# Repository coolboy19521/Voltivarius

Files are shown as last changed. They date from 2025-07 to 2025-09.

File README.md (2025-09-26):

# Voltivarius Komandasının Hesabatı




Bizim robotumuz **Raspberry Pi** bir-lövhəli kompüter ilə avtonom sürüş edir. Maneələri və hərəkətini təyin etmək üçün lidar, kamera, giroskop və məsafə sensorlarından istifadə edir. Robotun hərəkət etməsi üçün arxasında bir motor və bu motora qoşulmuş iki təkər vardır. Dönməsi üçünsə robotun qabağındakı servo motorundan və **Ackermann idarəetmə sistemindən** yararlanılır.

<h3>Komandamız</h3>

<table cellspacing="0" cellpadding="0" style="margin:0; padding:0; border-collapse:collapse;">
  <tr>
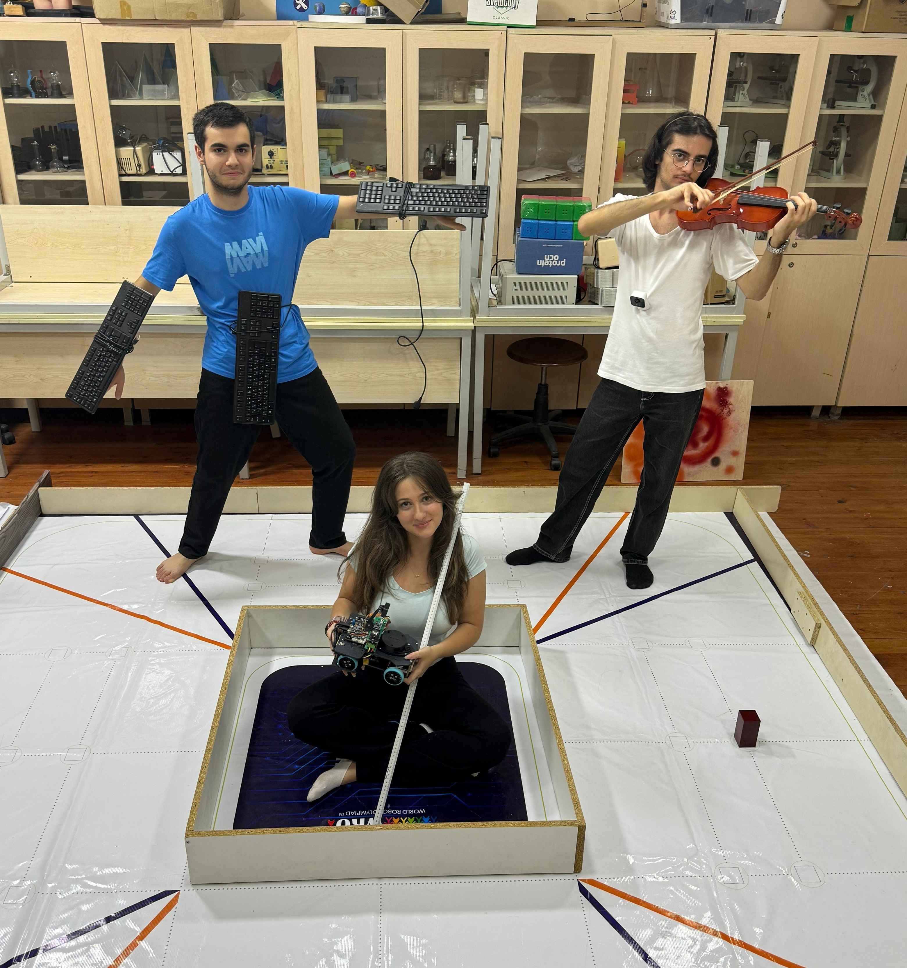
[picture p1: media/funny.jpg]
    <td style="margin:0; padding:0;"><br></td>
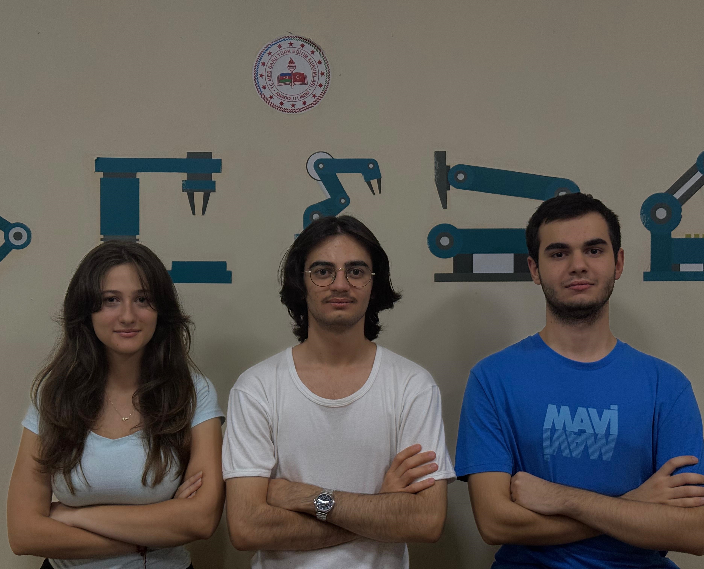
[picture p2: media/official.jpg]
    <td><br></td>
  </tr>
</table>

Komandamız **Əhməd Qəmbərli** (Proqramlaşdırma və strategiyanın təyin olunması; [ehmedqemberli09](mailto:ehmedqemberli09@gmail.com); rəsmi şəkildə sağda), **Melisa Yıldız** (Ümumi dizayn; [melisa.17.yildiz](mailto:melisa.17.yildiz@gmail.com); rəsmi şəkildə solda) və **Eyüp Şenal** (Elektronika, mexanika, detalların print olması və işlədilən məhsullar üçün bazar araşdırması; [arduinoaz2022](mailto:arduinoaz2022@gmail.com); rəsmi şəkildə mərkəzdə).

<h3>Robotumuz</h3>

<table cellspacing="0" cellpadding="0" style="margin:0; padding:0; border-collapse:collapse;">
  <tr>
    <td align="center" colspan="2">
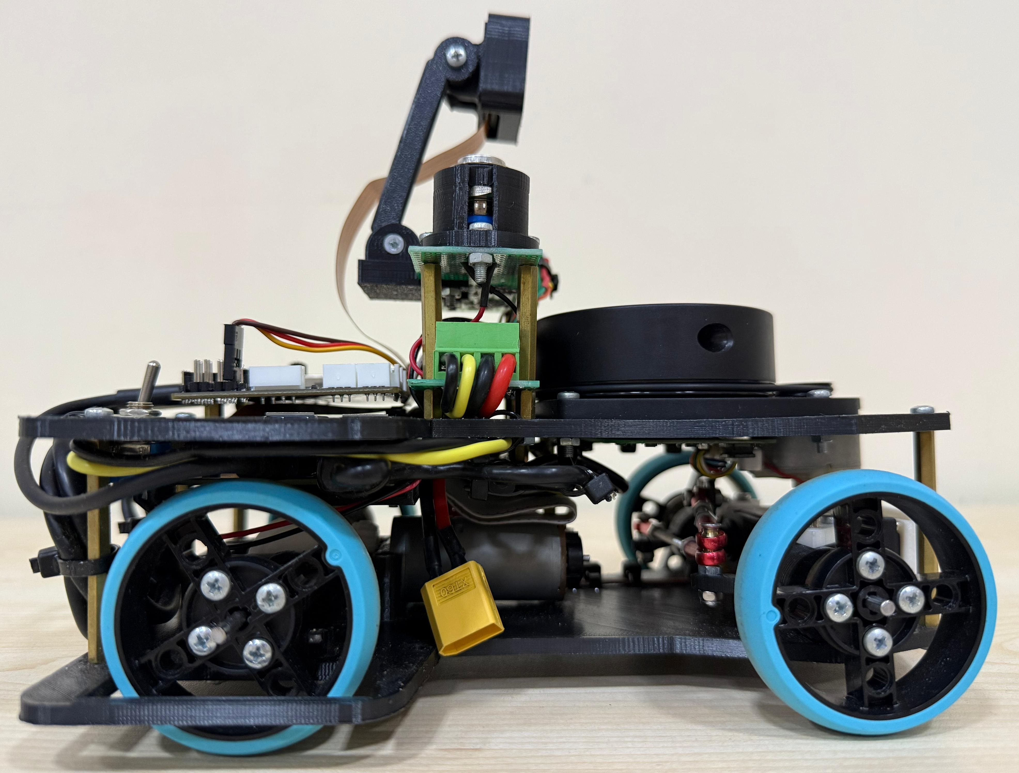
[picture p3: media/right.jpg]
      <br>
      <b>Sağ</b>
    </td>
    <td align="center" colspan="2">
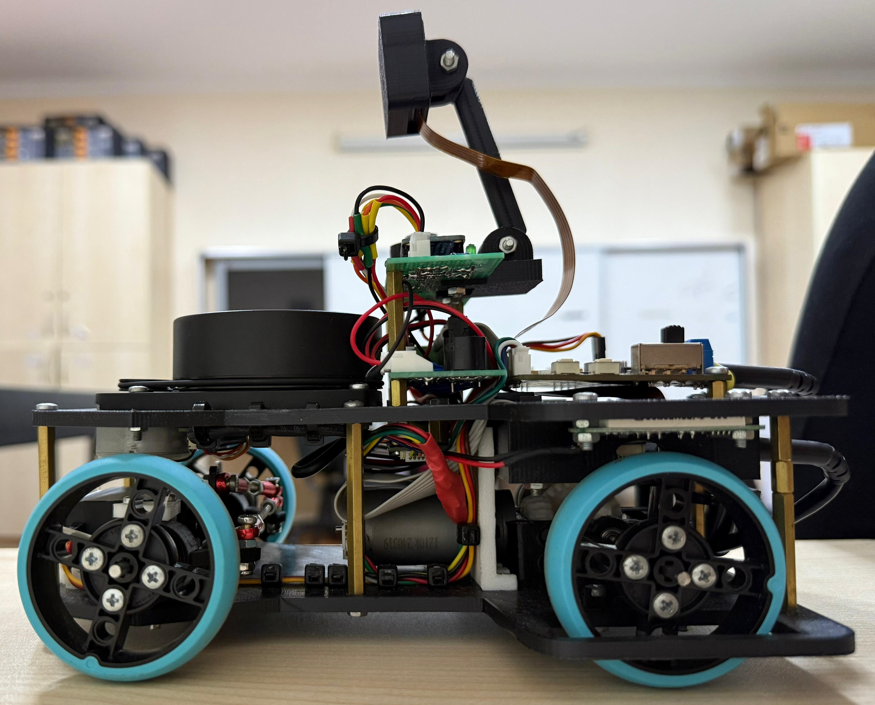
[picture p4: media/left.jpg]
      <br>
      <b>Sol</b>
    </td>
  </tr>
  <tr>
    <td align="center">
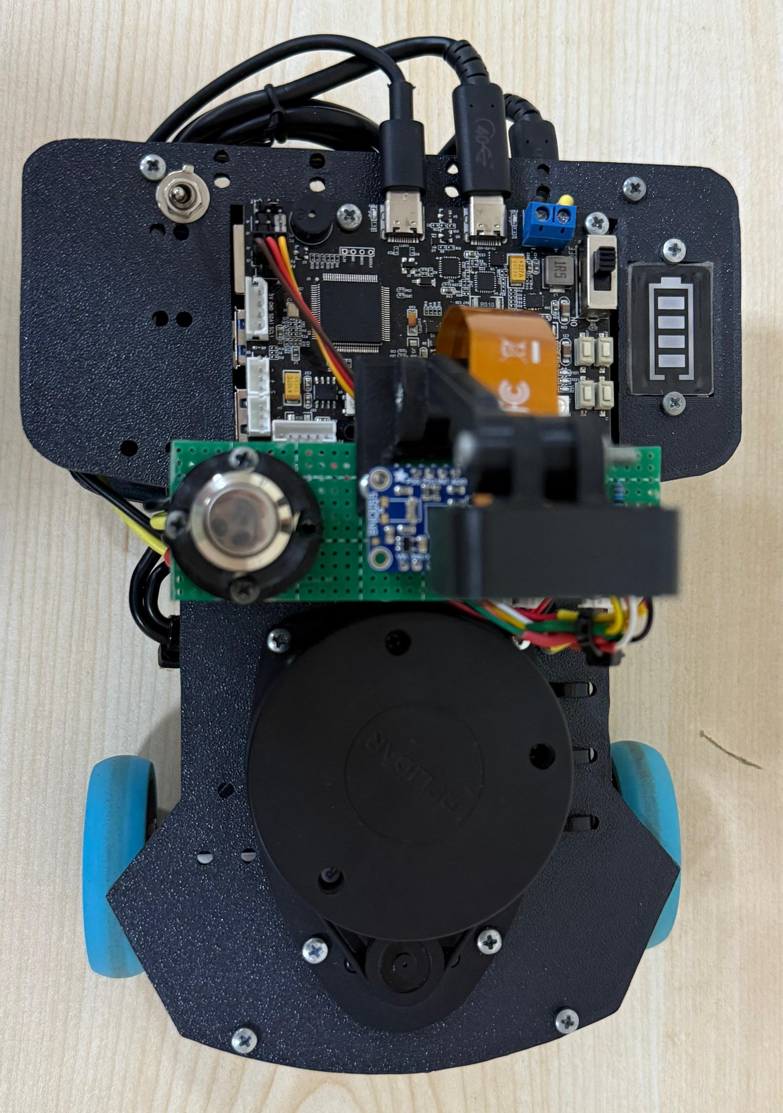
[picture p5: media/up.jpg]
      <br>
      <b>Üst</b>
    </td>
    <td align="center">
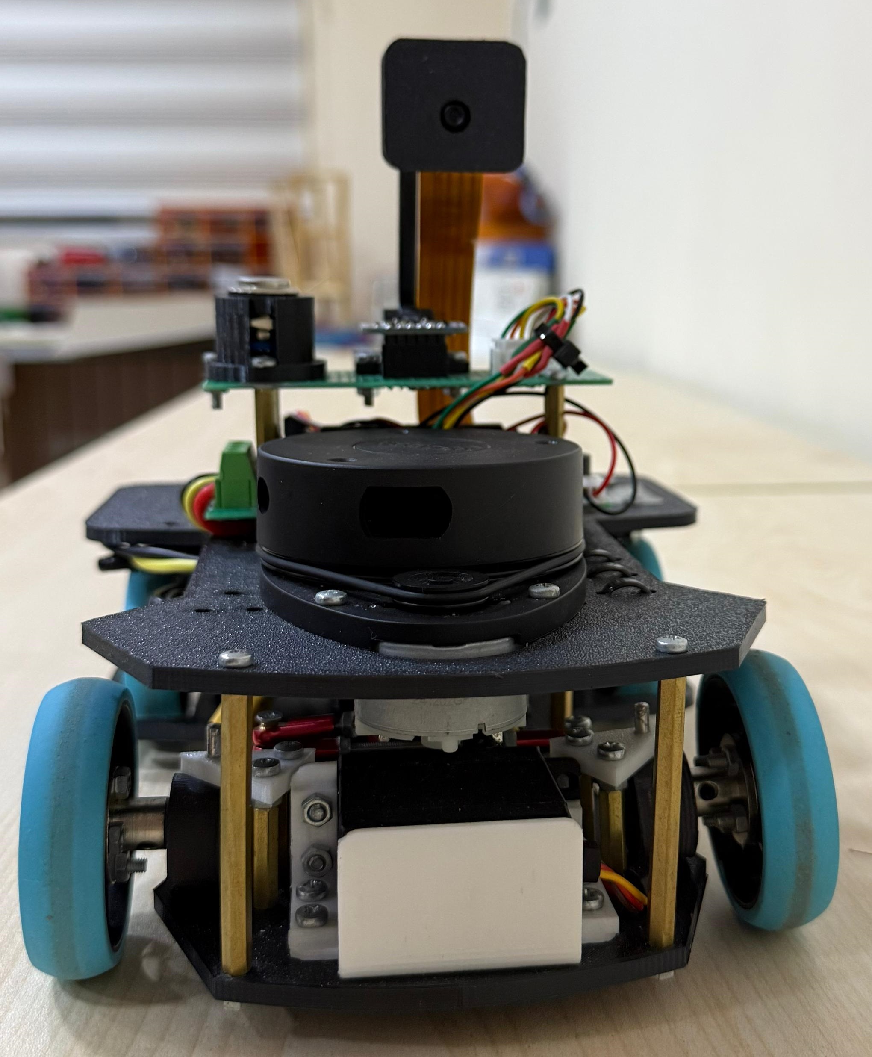
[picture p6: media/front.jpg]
      <br>
      <b>Qabaq</b>
    </td>
    <td align="center">
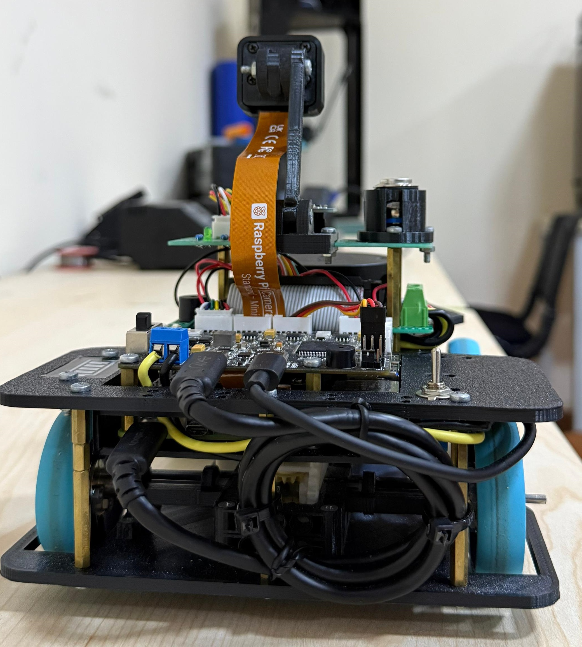
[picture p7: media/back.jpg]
      <br>
      <b>Arxa</b>
    </td>
    <td align="center">
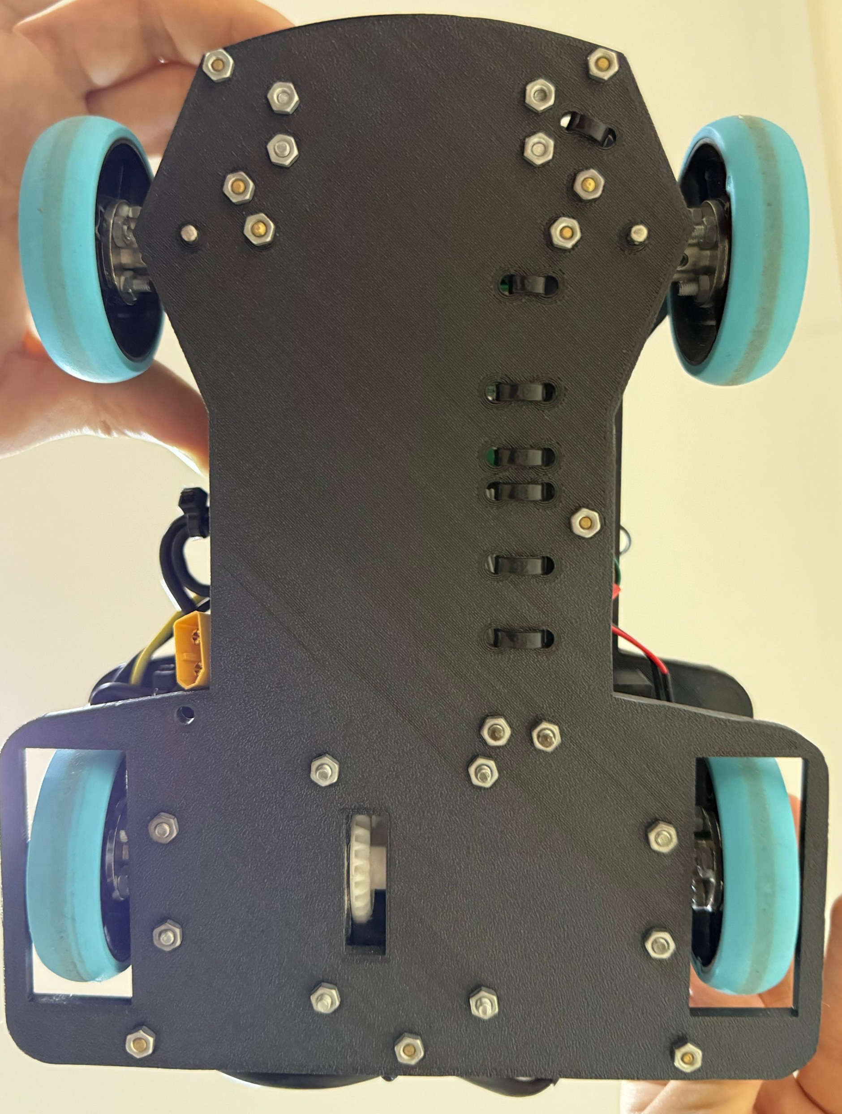
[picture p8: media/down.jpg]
      <br>
      <b>Alt</b>
    </td>
  </tr>
</table>

Robotumuz maneə mərhələsi üçün effektiv alqoritmdən istifadə edir. Belə ki, ilk tur bizim robot üçün öyrənmə turudur və biz bu turu yavaş yerinə yetiririk. Bu turda hədəfimiz bütün maneələrin rəngini düzgün görmək və maneələrə toxunmamaqdır. Bu turda maneələrin rəngi yadda saxlanılır. Buna görə də ikinci və üçüncü turlarda maneələrin rənginin oxunmasına ehtiyac qalmır. Beləcə birinci tur üçün `70 saniyə`, ikinci və üçüncü tur üçünsə sadəcə `30-35 saniyə` xərcləyirik.

### Hesabat Mündəricatı

### Mündəricat

- [Voltivarius Komandasının Hesabatı](#voltivarius-komandasının-hesabatı)
- [Komandamız](#komandamız)
- [Robotumuz](#robotumuz)
- [Elektronika](#robot-elektronikası)
  - [Sistemə baxış](#sistemə-baxış)
  - [Əsas komponentlər](#raspberry-pi-5)
    - [Raspberry Pi 5 və Pico](#raspberry-pi-5)
    - [LiDAR və Kamera](#lidar-sensor-rplidar-a1m8)
    - [IMU və Ultrasonik sensorlar](#gyroskop-imu-sensoru--adafruit-bno055)
  - [Enerji və qoruma sistemi](#batareyanın-xüsusiyyəti)
- [Mexanika](#mexanika-bölməsi)
  - [Əsas təkmilləşdirmələr](#əsas-təkmilləşdirmələr)
  - [Ölçülər və balans](#ölçülər-və-montaj-məntiqi)
  - [Mühərriklər və yerləşdirilməsi](#motor-növləri-və-xüsusiyyətləri)
  - [Sensorların mövqeləri](#lidar-və-kamera)
- [Proqram təminatı](#proqram-mühitinin-hazırlanması)
  - [Konfiqurasiya və paketlər](#raspberry-pi-konfiqurasiyası)
  - [Kodun test edilməsi](#kodun-işlədilməsi-və-test-edilməsi)
- [Strategiya](#strategiyanın-izahı)
- [Robotun videoları](#robotun-videoları)

# Robot elektronikası
### Materialların siyahısı

<table>
  <tr>
    <th>Komponentlər</th><th>Şəkil</th>
    <th>Komponentlər</th><th>Şəkil</th>
  </tr>

  <tr>
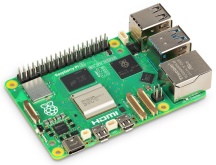
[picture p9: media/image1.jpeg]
    <td>Raspberry Pi 5 x 1</td><td></td>
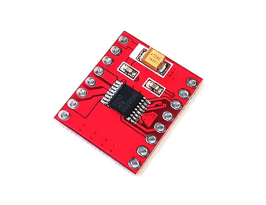
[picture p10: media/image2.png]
    <td>Motor Sürücü x 1</td><td></td>
  </tr>

  <tr>
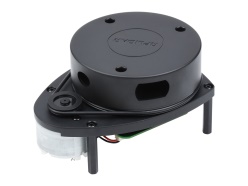
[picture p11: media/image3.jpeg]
    <td>RPLidar-A1M8 x 1</td><td></td>
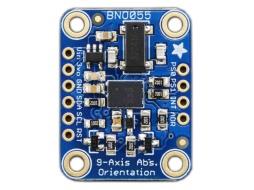
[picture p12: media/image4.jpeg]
    <td>BNO055 x 1</td><td></td>
  </tr>

  <tr>
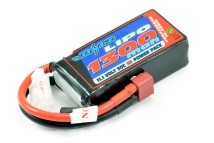
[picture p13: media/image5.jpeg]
    <td>3s Li-Po x 1</td><td></td>
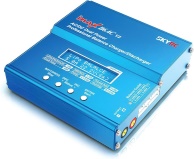
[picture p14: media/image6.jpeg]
    <td>IMAX B6AC batareya doldurucu x 1</td><td></td>
  </tr>

  <tr>
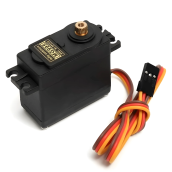
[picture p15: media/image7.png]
    <td>MG995 Servo Motor x 1</td><td></td>
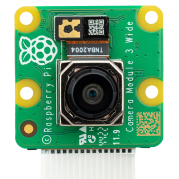
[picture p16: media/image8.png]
    <td>Raspberry Pi Kamera Modulu 3 x 1</td><td></td>
  </tr>

  <tr>
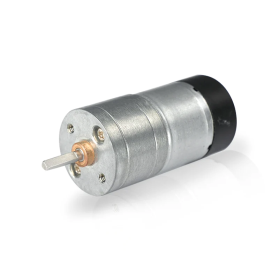
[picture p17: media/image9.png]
    <td>Enkoder mühərriki x 1</td><td></td>
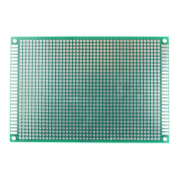
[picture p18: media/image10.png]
    <td>Perfboard x 1</td><td></td>
  </tr>

  <tr>
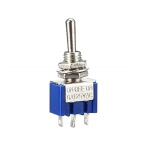
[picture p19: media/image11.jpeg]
    <td>Dəyişdiricini ON-OFF x 1</td><td></td>
    <td>2,54 mm JST-XH Bağlayıcı Kişi x 5</td><td></td>
  </tr>

  <tr>
    <td>2,54 mm JST-XH Konnektor Dişi x 5</td><td></td>
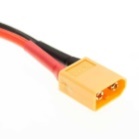
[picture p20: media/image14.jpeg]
    <td>XT-60 x 1</td><td></td>
  </tr>

  <tr>
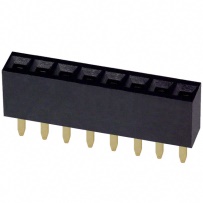
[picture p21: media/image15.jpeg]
    <td>2.54 mm Pin Başlığı Dişi x 1</td><td></td>
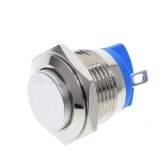
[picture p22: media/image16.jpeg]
    <td>Düymə x 1</td><td></td>
  </tr>

  <tr>
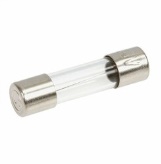
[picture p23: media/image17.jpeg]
    <td>Sigorta x 1</td><td></td>
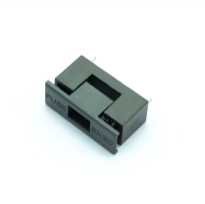
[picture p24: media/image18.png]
    <td>Sigorta Tutucusu x 1</td><td></td>
  </tr>

  <tr>
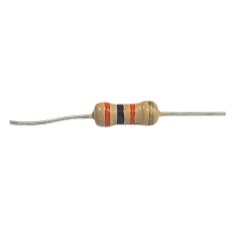
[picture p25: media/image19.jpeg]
    <td>10K ohm Rezistor x 1</td><td></td>
    <td>330ohm rezistor x 2</td><td></td>
  </tr>

  <tr>
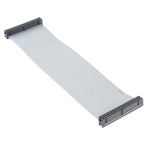
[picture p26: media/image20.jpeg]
    <td>GPIO kabeli x 1</td><td></td>
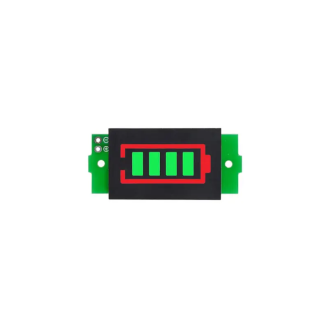
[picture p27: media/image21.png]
    <td>Batareya monitoru x 1</td><td></td>
  </tr>

  <tr>
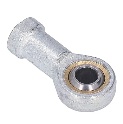
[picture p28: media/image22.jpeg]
    <td>Bilyalı birləşmə x 4</td><td></td>
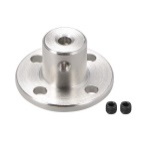
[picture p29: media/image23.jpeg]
    <td>3 mm sərt flanşlı mufta x 4</td><td></td>
  </tr>

  <tr>
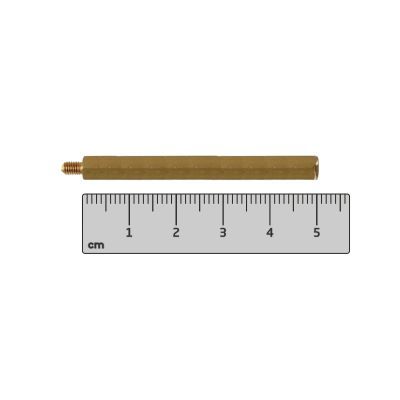
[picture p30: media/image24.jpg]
    <td>50 mm Standoff Qadın-Kişi x 6</td><td></td>
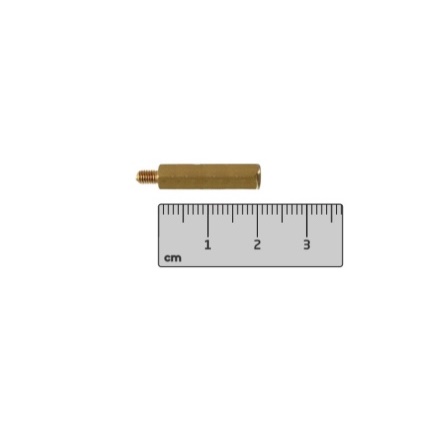
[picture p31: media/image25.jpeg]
    <td>20mm Standoff Qadın - Kişi x 4</td><td></td>
  </tr>

  <tr>
    <td>3 mm mil 7 sm x 2</td><td></td>
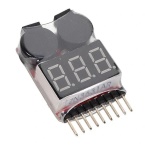
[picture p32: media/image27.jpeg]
    <td>Li-Po Batareya Test Cihazı Gərginlik Monitoru x 1</td><td></td>
  </tr>

  <tr>
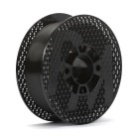
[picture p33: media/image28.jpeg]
    <td>Filament 1 kq x 1</td><td></td>
    <td>M3 Neylon Daxiletmə Kilid Qoz x 2</td><td></td>
  </tr>

  <tr>
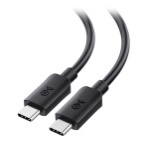
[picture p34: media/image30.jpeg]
    <td>Type-c - Type-c Kabel x 1</td><td></td>
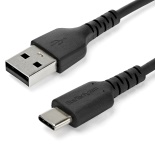
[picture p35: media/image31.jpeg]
    <td>Type-c - USB Kabel x 1</td><td></td>
  </tr>

  <tr>
    <td>32 GB Yaddaş Kartı x 1</td><td></td>
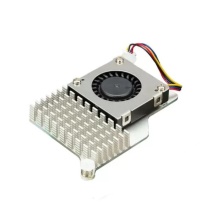
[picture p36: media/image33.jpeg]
    <td>Aktiv soyuducu x 1</td><td></td>
  </tr>

  <tr>
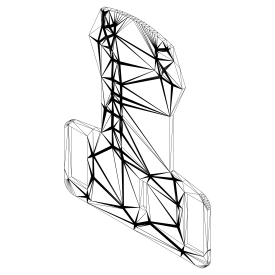
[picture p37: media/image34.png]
    <td>Avtomobil Şassisinin Aşağı hissəsi x 1</td><td></td>
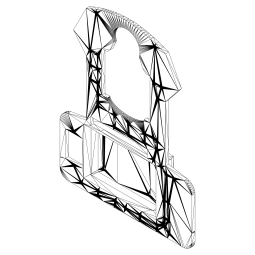
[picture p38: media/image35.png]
    <td>Avtomobilin şassisinin yuxarı hissəsi x 1</td><td></td>
  </tr>

  <tr>
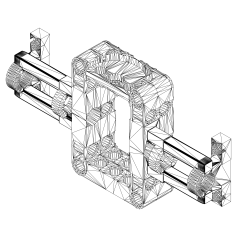
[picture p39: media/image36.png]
    <td>Motor qutusu x 1</td><td></td>
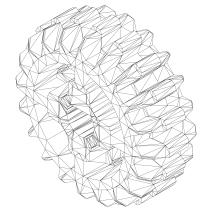
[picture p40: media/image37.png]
    <td>Motor qutusu təkəri x 1</td><td></td>
  </tr>

  <tr>
    <td>Motor qutusu Təkər 2 x 1</td><td></td>
    <td>Sürət qutusu təkəri x 4</td><td></td>
  </tr>

  <tr>
    <td>Servo braket x 1</td><td></td>
    <td>Təkər Sükan Sistemi x 2</td><td></td>
  </tr>

  <tr>
    <td>Ön Təkər Tutacağı x 2</td><td></td>
    <td>Kabel tutacağı x 1</td><td></td>
  </tr>

  <tr>
    <td>Düymə Sahibi x 1</td><td></td>
    <td>Kamera Tutacağı x 1</td><td></td>
  </tr>

  <tr>
    <td>XL-4015 x 2</td><td></td>
    <td>HCSR-04 x 1</td><td></td>
  </tr>
</table>

### Sistemə baxış
### Elektron Sistemin Arxitekturası

- **Raspberry Pi 5:** Sensor məlumatlarını toplayır, emal edir və aktuator əmrləri yaradır.
- **Raspberry Pi Pico + DRV8833:** DC motor və servoları idarə edir, enkoder məlumatlarını geri ötürür.
- **Enkoderli DC Motor:** İrəli-geri hərəkəti təmin edir və sürət/mövqe məlumatı verir.
- **Servo Motor:** Robotun dönüşlərini idarə edir.

### İş Prinsipi
-	Enerji Li-Po 3S batareyadan təmin olunur.
-	Raspberry Pi 5 işə düşür və ROS qovşaqları aktivləşir.
-	Sensorlardan (lidar, kamera) məlumat alınır.
-	Pi 5 məlumatları emal edir və qərar qəbul edir.
-	Əmrlər Pico vasitəsilə DRV8833-ə ötürülür.
-	Motorlar və servo hərəkəti icra edir.
-	Sistem real vaxt rejimində dövr edir.

<h3>Raspberry Pi 5</h3>

<table style="width:80%; border-collapse:collapse;">
  <tr>
    <td rowspan="4" style="width:400px; text-align:center; vertical-align:middle; padding:0; margin:0;">
      
    </td>
    <td>USB</td>
    <td>LiDAR sensoru və əlavə cihazların birləşdirilməsi</td>
  </tr>
  <tr>
    <td>CSI Kamera Poru:</td>
    <td>Kamera Modulu 3 üçün qoşulma</td>
  </tr>
  <tr>
    <td>GPIO sancaqları</td>
    <td>Başlat düyməsi, güc açarı, kodlayıcı və digər sensor siqnalları</td>
  </tr>
  <tr>
    <td>İş gərginliyi</td>
    <td>5V DC, minimum 3A</td>
  </tr>
</table>

Raspberry Pi 5 robotun əsas nəzarətçisi kimi istifadə olunan yüksək performanslı bir lövhəli kompüterdir. Sensor məlumatlarını emal edir, aktuatorlara nəzarət siqnalları yaradır və ümumi sistem əməliyyatlarını ROS üzərindən idarə edir.

Robotumuzda rolu:

- RPLiDAR A1M8 və Kamera Modulu 3-dən məlumatların emalı
- Raspberry Pi Pico vasitəsilə motorların və servoların idarəsi
- Başlat düyməsi və güc açarı üçün GPIO istifadə

Güc Tələbləri:

- Li-Po 3S 1300 mAh batareya və gərginlik tənzimləyicisi ilə təchiz olunur
- Periferik cihazlar üçün sabit enerji təmin edir

<h3>Raspberry Pi Pico + DRV8833 Motor Sürücü</h3>

<table style="width:80%; border-collapse:collapse;">
  <tr>
    <td rowspan="5" style="width:300px; text-align:center; vertical-align:middle; padding:0; margin:0;">
      
    </td>
    <td>RP2040 mikronəzarətçi (Pico)</td>
  </tr>
  <tr>
    <td>Dual H-Bridge motor sürücü (DRV8833)</td>
  </tr>
  <tr>
    <td>Enkoder oxunuşları üçün dəstək</td>
  </tr>
  <tr>
    <td>PWM ilə sürət və istiqamət idarəsi</td>
  </tr>
  <tr>
    <td>Kompakt ölçü və aşağı enerji istehlakı</td>
  </tr>
</table>

Raspberry Pi Pico mikronəzarətçisi DRV8833 motor sürücüsü ilə birlikdə DC mühərrikləri və servoları idarə etmək üçün istifadə olunur. Əsas nəzarətçi olan Raspberry Pi 5-dən gələn əmrləri qəbul edir və aktuator hərəkətlərinə çevirir.

Mühərrik Birləşmələri
-	2 kanal DC mühərrik idarəsi
-	PWM siqnalları ilə sürət və istiqamət nəzarəti
-	Enkoderlərdən sürət və mövqe rəyi

Güc Tələbləri
-	**DRV8833:** 2.7–10.8V giriş
-	**Raspberry Pi Pico:** 3.3V işləmə gərginliyi

<h3>Mühərriklər və Servo Motor</h3>

<h4>Mühərrik</h4>

<table style="width:80%; border-collapse:collapse;">
  <tr>
    <td rowspan="5" style="width:400px; text-align:center; vertical-align:middle; padding:0; margin:0;">
      
    </td>
    <td>İş gərginliyi</td>
    <td>5–12V DC</td>
  </tr>
  <tr>
    <td>Enkoder gərginliyi</td>
    <td>3.3–5V DC</td>
  </tr>
  <tr>
    <td>Yüksüz cərəyan</td>
    <td>200 mA, nominal: 300 mA, dayanma: 800 mA</td>
  </tr>
  <tr>
    <td>Sürət</td>
    <td>~1000 RPM @ 12V</td>
  </tr>
  <tr>
    <td>Ölçü</td>
    <td>25 × 71 mm, Çəki: 95 q</td>
  </tr>
</table>

<h4>Servo</h4>

<table style="width:80%; border-collapse:collapse;">
  <tr>
    <td rowspan="4" style="width:400px; text-align:center; vertical-align:middle; padding:0; margin:0;">
      
    </td>
    <td>Fırlanma bucağı</td>
    <td>30°–160°</td>
  </tr>
  <tr>
    <td>Sürət</td>
    <td>0.15 s/60°</td>
  </tr>
  <tr>
    <td>Tork</td>
    <td>13–15 kg·cm</td>
  </tr>
  <tr>
    <td colspan="2">Metal dişli, yüksək davamlılıq</td>
  </tr>
</table>

Əlaqələr və İnteqrasiya
-	**DC mühərriklər:** DRV8833 vasitəsilə idarə olunur
-	**Enkoderlər:** Pico üzərindən Pi 5-ə məlumat göndərir
-	**Servo:** PWM ilə nəzarət

Güc Tələbləri
-	**DC mühərriklər:** 5–12V DC
-	**Servo:** 4.8–6V DC

Nəzarət Siqnalları
-	**DC mühərriklər:** PWM + Enkoder rəyi
-	**Servo:** PWM ilə mövqe bucağı idarəsi

<h3>LiDAR Sensor (RPLIDAR A1M8)</h3>

<table style="width:80%; border-collapse:collapse;">
  <tr>
    <td rowspan="5" style="width:330px; text-align:center; vertical-align:middle; padding:0; margin:0;">
      
    </td>
    <td>Ölçü</td>
    <td>98.5 × 70 × 60 mm</td>
  </tr>
  <tr>
    <td>Çəki</td>
    <td>170 q</td>
  </tr>
  <tr>
    <td>Tarama diapazonu</td>
    <td>6 m</td>
  </tr>
  <tr>
    <td>Nümunə götürmə sürəti</td>
    <td>8000/s</td>
  </tr>
  <tr>
    <td>Tarama tezliyi</td>
    <td>2–10 Hz (PWM ilə)</td>
  </tr>
</table>

SLAMTEC RPLiDAR A1M8, xəritəçəkmə və naviqasiya üçün nəzərdə tutulmuş 360° 2D lazer skaneridir. Yüngül, etibarlı və mobil robotlar üçün optimallaşdırılmışdır.

Əlaqələr
-	USB interfeysi ilə Raspberry Pi 5-ə qoşulur
-	PWM ilə motor sürəti tənzimlənir

Güc Tələbləri
-	5V DC (USB)
-	Aşağı enerji istehlakı

<h3>Kamera (Raspberry Pi Camera Module v3)</h3>

<table style="width:80%; border-collapse:collapse;">
  <tr>
    <td rowspan="4" style="width:280px; text-align:center; vertical-align:middle; padding:0; margin:0;">
      
    </td>
    <td>Çözünürlük</td>
    <td>4608 × 2592 (11.9 MP)</td>
  </tr>
  <tr>
    <td>Piksel</td>
    <td>1.4 µm</td>
  </tr>
  <tr>
    <td>Video</td>
    <td>1080p50, 720p100, 480p120</td>
  </tr>
  <tr>
    <td>Ölçü</td>
    <td>25 × 24 × 11.5 mm, Çəki: 3 q</td>
  </tr>
</table>

Sony IMX708 sensorlu 11.9 MP kamera modulu, yüksək keyfiyyətli təsvir və video çəkmə imkanına malikdir. HDR və PDAF avtofokus dəstəkləyir.

Əlaqələr
-	CSI-2 portu ilə Raspberry Pi 5-ə qoşulur

Güc Tələbləri
-	CSI interfeysi üzərindən enerji alır

<h3>Gyroskop (IMU) Sensoru – Adafruit BNO055</h3>

<table style="width:80%; border-collapse:collapse;">
  <tr>
    <td rowspan="4" style="width:310px; text-align:center; vertical-align:middle; padding:0; margin:0;">
      
    </td>
    <td>9 DOF</td>
    <td>Akselerometr, Giroskop, Maqnitometr</td>
  </tr>
  <tr>
    <td>Çıxış</td>
    <td>Euler bucaqları, Kvaternion, Vektorlar</td>
  </tr>
  <tr>
    <td>Tezlik</td>
    <td>100 Hz-ə qədər</td>
  </tr>
  <tr>
    <td>Ölçü</td>
    <td>20 × 27 × 4 mm, Çəki: 3 q</td>
  </tr>
</table>

Bosch BNO055 əsaslı IMU sensoru daxili sensor birləşməsi ilə dəqiq oriyentasiya məlumatı təqdim edir.

Əlaqələr
-	**Rabitə:** I²C (0x28 və ya 0x29), UART dəstəyi
-	Reset və Interrupt pinləri

Güc Tələbləri
-	**İş gərginliyi:** 3.3V (5V tolerant I²C girişləri ilə)

<h3>Xüsusi PCB Dizaynı</h3>

Bu xüsusi idarəetmə lövhəsi Raspberry Pi 5 və robot sisteminin periferik komponentləri arasında əsas interfeys kimi hazırlanmışdır. O, modullar arasında mütəşəkkil və təhlükəsiz əlaqəni təmin edən sensor birləşmələrini, istifadəçinin qarşılıqlı əlaqə elementlərini (LED, düymə, səs siqnalı) və enerji idarəetmə komponentlərini birləşdirir.

**Bir qatlı perfboard (prototip lövhəsi)** üzərində qurulmuşdur və aşağıdakı əsas komponentləri ehtiva edir:
-	**İki LED (qırmızı və yaşıl):** Vəziyyət və xəbərdarlıq göstəriciləri kimi istifadə olunur.
-	**Bir siqnal:** Səsli xəbərdarlıqlar verir.
-	**Bir təkan düyməsi:** İstifadəçi girişinə nəzarət.
-	**Bir qoruyucu:** Həddindən artıq cərəyandan qorunma.
-	**Bir giroskop sensoru (BNO055 IMU):** Oriyentasiya və hərəkət sensoru.
-	**Bir açar:** Gücü yandırma/söndürmə nəzarəti.
-	**Raspberry Pi 5 GPIO əlaqələri:** Sistemə nəzarət və rabitə üçün.

Perfboardda elektrik xətləri qalın mis naqillərlə, siqnal xətləri isə daha incə naqillərlə, cərəyanı idarə etmək qabiliyyətini təmin etmək və müdaxiləni minimuma endirmək üçün çəkilir.

Bağlantı nöqtələri
-	**Güc Girişi:** 6–14 V xarici enerji təchizatı ilə işləyir .
-	**Raspberry Pi 5 GPIO:** LEDlər, düymələr, səs siqnalları və sensor üçün birbaşa bağlantılar.
-	**Sensor bağlantısı:** BNO055 IMU I²C interfeysi (SCL, SDA) vasitəsilə Raspberry Pi 5-ə qoşulur .
-	**Bağlayıcılar:** JST və pin başlıq bağlayıcıları həm güc, həm də siqnal interfeysləri üçün istifadə olunur.

İstehsal və montaj qeydləri
-	Dövrə əl ilə perfboard (prototip lövhəsi) üzərində yığılır .
-	Elektrik xətləri yüksək cərəyan üçün daha qalın naqillərlə lehimlənir, siqnal xətləri isə daha nazik naqillərdən istifadə edir.
-	Prototip olaraq bu dizayn tez modifikasiyalara və sınaqlara imkan verir.
-	Uzunmüddətli və davamlı istifadə üçün, kütləvi istehsalda lehim maskası və səthi bitirmə ilə FR4 əsaslı PCB- yə keçmək tövsiyə olunur.

<h3>Ultrasonik Sensor (HC-SR04)</h3>

<table style="width:80%; border-collapse:collapse;">
  <tr>
    <td rowspan="7" style="width:275px; text-align:center; vertical-align:middle; padding:0; margin:0;">
      
    </td>
    <td>Ölçmə diapazonu</td>
    <td>2 sm – 400 sm</td>
  </tr>
  <tr>
    <td>Ölçmə dəqiqliyi</td>
    <td>±3 mm</td>
  </tr>
  <tr>
    <td>Ölçmə bucağı</td>
    <td>~15°</td>
  </tr>
  <tr>
    <td>İş gərginliyi</td>
    <td>5V DC</td>
  </tr>
  <tr>
    <td>Ölçülər</td>
    <td>45 × 20 × 15 mm</td>
  </tr>
  <tr>
    <td>Çəki</td>
    <td>9 g</td>
  </tr>
  <tr>
    <td colspan="2">Sürətli cavab müddəti (təxminən 10 µs trigger impulsu)</td>
  </tr>
</table>

HC-SR04, maneələrin aşkarlanması və yaxın məsafələrin ölçülməsi üçün istifadə olunan ucuz və geniş yayılmış ultrasonik məsafə sensorudur. O, səs dalğalarının əks olunma prinsipinə əsaslanır və qısa məsafəli obyekt aşkarlanmasında yüksək dəqiqlik təmin edir.

Əlaqələr
-	**VCC (5V):** Raspberry Pi və ya RRC Lite Controller-in 5V xəttinə qoşulur.
-	**GND:** Ümumi torpaq xəttinə qoşulur.
-	**TRIG (Trigger):** Raspberry Pi GPIO pininə çıxış siqnalı üçün qoşulur.
-	**ECHO:** Raspberry Pi GPIO pininə giriş siqnalı üçün qoşulur.

> Qeyd: ECHO pinindən gələn 5V siqnalı Raspberry Pi GPIO (3.3V tolerant) üçün uyğunlaşdırmaq məqsədilə gərginlik bölücü rezistor istifadə olunmalıdır.

Güc Tələbləri
-	**İş gərginliyi:** 5V DC
-	**Tipik cərəyan istehlakı:** 15 mA

<h3>Batareyanın Xüsusiyyətləri (Gərginlik, Tutum, C Qiyməti)</h3>

<table style="width:80%; border-collapse:collapse;">
  <tr>
    <td rowspan="8" style="width:400px; text-align:center; vertical-align:middle; padding:0; margin:0;">
      
    </td>
    <td>Gərginlik</td>
    <td>11.1 V (nominal)</td>
  </tr>
  <tr>
    <td>Tutum</td>
    <td>1300 mAh</td>
  </tr>
  <tr>
    <td>Hüceyrə sayı</td>
    <td>3S (3 hüceyrə, seriyalı)</td>
  </tr>
  <tr>
    <td>Boşaltma dərəcəsi</td>
    <td>50C davamlı / 100C pik (maksimum 10 s)</td>
  </tr>
  <tr>
    <td>Çəki</td>
    <td>110 g</td>
  </tr>
  <tr>
    <td>Ölçülər</td>
    <td>74 × 33 × 21 mm</td>
  </tr>
  <tr>
    <td>Boşaltma konnektoru</td>
    <td>XT60 (qara)</td>
  </tr>
  <tr>
    <td>Doldurma konnektoru</td>
    <td>JST-XHR (ağ)</td>
  </tr>
</table>

Layihədə istifadə olunan enerji mənbəyi — yüksək cərəyan tələb edən robototexnika, dron və müdafiə sistemləri üçün nəzərdə tutulmuş JetFire 3S Li-Po batareyasıdır. Bu batareya yüksək boşalma dərəcəsi və etibarlı hüceyrə quruluşu ilə sistemin sabit və uzunmüddətli işləməsini təmin edir.

<h3>Güc Paylama Diaqramı və Mühafizə Sistemləri</h3>

11.1V 3S Li-Po batareyası bütün sistemi təmin edir. Enerji mərkəzi paylama lövhəsi vasitəsilə bölünərək yüksək cərəyan xətləri (mühərriklər, sürücülər) və aşağı cərəyan xətləri (nəzarətçilər, sensorlar) ayrılır. Bu, həm səmərəliliyi artırır, həm də sistemdə gərginlik sabitliyini təmin edir.

Gərginlik Tənzimləyiciləri və Çeviricilər (5V, 3.3V və s.)
-	**5V:** Raspberry Pi 5, LiDAR və kamera üçün təmin edilir.
-	**3.3V:** IMU və digər aşağı güclü sensorlar üçün istifadə olunur.
-	**XL4015 Çevirici:**
  - DRV8833 sürücü lövhəsi üçün 10V çıxış təmin edir.
  -	Servo motor üçün 6V çıxış təmin edir.

Səmərəlilik və enerji sabitliyi üçün keçid tənzimləyicilərindən istifadə olunub.

BMS Li-Po batareyasının təhlükəsiz işləməsini təmin edir:
-	Həddindən artıq yüklənmənin qarşısını alır,
-	Həddindən artıq boşalmadan qoruyur,
-	Qısaqapanma və qızdırma risklərini azaldır.

Balanslaşdırılmış doldurma **iMAX B6AC balans şarj cihazı** vasitəsilə həyata keçirilir.

Mühafizə Mexanizmləri (Qoruyucu, Həddindən Artıq Cərəyandan Qorunma)
-	Qoruyucular və çox qoruyucu sxemlər əlavə olunub.
-	Tərs polarite qorunması və gərginlik monitorinq modulları istifadə edilib.
-	Parazitlənmənin qarşısını almaq üçün mühərrik xətlərinə kapasitörlər qoşulub. Bu, motorların işini sabitləşdirir və siqnal qarışıqlığını minimuma endirir.

<h3>Dövrə Sxemləri</h3>

<table cellspacing="0" cellpadding="0" style="margin:0; padding:0; border-collapse:collapse;">
  <tr>
    <td style="margin:0; padding:0;"><br></td>
    <td><br></td>
  </tr>
  <tr>
    <td align="center">Raspberry Pi və sensorlar üçün dövrə sxemi</td>
    <td align="center">Raspberry Pi Pico və motor sürücü üçün dövrə sxemi</td>
  </tr>
</table>

# Mexanika Bölməsi

Yarışmaya başladıqdan bəri robotumuz hər zaman dəyişmişdir. Bunun səbəbi dəyişən elektronik dövrələr, dəyişən strategiyalara edilən adaptasiyalardır. İlk prototipimiz daha kəskin xətləri olan, kompakt və sıx şasseyə sahib idi və bu səbəbdən robot obyektlərə dəyərək hərəkət edirdi. Zamanla şassi ölçüləri genişləndi, xətləri hamarlaşdı və daha çox stabil və etibarlı struktura çevrildi.

### Əsas təkmilləşdirmələr

Robot şassi, motor və idarəetmə sistemləri optimallaşdırılmışdır. Xüsusilə stabil şassi quruluşu və sensor yerləşimi üzərində dəyişikliklər aparılmış, beləliklə robotun balansı və çevikliyi artırılmışdır. Bundan əlavə robotun kamera moduluna 4 ədəd ağ LED əlavə edilmişdir. Bu LEDlər işıqlandırmanı sabitləşdirərək ətraf işıqlandırmanın təsirini azaldır.

<br>

Robotun şassisi həm yüngül, həm də möhkəm olması üçün diqqətlə seçilmiş materiallardan hazırlanıb. Burada əsasən alüminium, PLA plastik və polikarbonatdan istifadə olunub. Bu materiallar sayəsində robot həm dayanıqlılığını qoruyur, həm də sərbəst və çevik hərəkət edə bilir.

Konstruksiya zamanı modulyarlıq və uzunömürlülük əsas prinsiplər kimi götürülüb. Şassinin forması və təbəqələri elə qurulub ki, elektrik komponentləri və sensorlar həm müdafiə altında olsun, həm də möhkəm şəkildə bərkidilsin.

Dizayn prosesi zamanı komponentlərin düzgün yerləşməsi və robotun sabit hərəkəti əsas hədəf olub. Enerji bloku, sensorlar, aktuatorlar və nəzarətçi vahidinin mövqeləri bir-birinə mane olmadan, səmərəli şəkildə yerləşdirilib. Bu yanaşma həm mexaniki, həm də elektron sistemlərin bir-birinə qarışmadan, ahəngdar şəkildə işləməsinə imkan yaradır.

### Ölçülər və Montaj Məntiqi
Robotun şassisi `28 sm` ölçüsündədir və komponentlərin yerləşdirilməsi üçün montaj deşikləri və aralayıcı standoff-lar nəzərə alınmışdır. Ümumilikdə 5 ədəd standoff istifadə olunmuşdur ki, şassinin üst və alt hissələri möhkəm şəkildə birləşdirilsin və eyni zamanda asan açılıb-bağlanma imkanı olsun. Bu, həm texniki xidmət, həm də modul dəyişdirmə proseslərini sadələşdirir.

Komponentlərin yerləşdirilməsi çox həssas şəkildə planlaşdırılmışdır:
-	Ön hissədə LIDAR,
-	Robotun ortasında Gyro sensoru,
-	Arxasında Raspberry Pi 5 və motor sürücü,
-	Ən arxa hissədə ultrasonik sensor yerləşdirilmişdir.

Bu yerləşdirmə sensorların optimal işləməsini və robotun stabil hərəkətini təmin edir. Komponentlər arasındakı məsafələr həm mexaniki müdaxiləni minimuma endirir, həm də istilik və vibrasiya kimi təsirlərin qarşısını alır.

3D Print Tövsiyəsi:
-	**İstifadə olunan filament:** PLA (Creality şirkətinə məxsus),
-	**Printer:** Sidewinder X2,
-	**Nozzle temperaturu:** 210°C,
-	**Tabla temperaturu:** 60°C,
-	Standoff aralayıcıları və vidalar şassinin möhkəmliyini və rahat montajını təmin edir.

<table cellspacing="0" cellpadding="0" style="margin:0; padding:0; border-collapse:collapse;">
  <tr>
    <td style="margin:0; padding:0;"><br></td>
    <td><br></td>
  </tr>
  <tr>
    <td colspan="2" align="center">Üst, yan və alt görünüş.</td>
  </tr>
</table>

### Motor Növləri və Xüsusiyyətləri

Robotun hərəkət və dəqiqlik tələblərinə uyğun olaraq iki əsas motor növü istifadə olunmuşdur:
-	**DC dişli mühərrikləri:** Bu mühərriklər 5–12V DC diapazonunda işləyir və yüksək tork təmin edir. Hər bir motorun cərəyan və RPM xüsusiyyətləri robotun sürət və yük daşıma qabiliyyətinə uyğun seçilmişdir. Dişli sistemi mühərrikin çıxış sürətini optimallaşdıraraq, daha hamar və dəqiq hərəkət təmin edir.
-	**Servo motorlar:** Servo motorlar robotun dönmə bucağı və dəqiq mövqe idarəsini təmin edir. Bu motorlar 4.8–6V DC ilə işləyir və yüksək tork tələb edən kiçik hərəkətlər üçün istifadə olunur. Servo motorların sürəti və dəqiqliyi robotun navigasiya və sensor yönləndirmə funksiyalarında kritik rol oynayır.

### Motorların Robot Hərəkətinə Təsiri

Motorların xüsusiyyətləri robotun ümumi performansına birbaşa təsir edir:
-	**Hərəkət sürəti:** DC mühərriklərinin RPM-i robotun sürətini təyin edir.
-	**Tork tələbləri:** Robotun şassisi və daşıdığı komponentlər nəzərə alınaraq motorlar seçilmişdir ki, həm sabit hərəkət, həm də yüklə maneələrdən keçmə imkanı təmin olunsun.
-	**Yük daşıma qabiliyyəti:** Motorlar robotun əlavə sensor və akkutator çəkisini dəstəkləyəcək gücdə olmalıdır.

### Mühərriklərin Mövqeləşdirilməsi

Motorların şassidə yerləşdirilməsi robotun balansı və hərəkət səmərəliliyi üçün diqqətlə planlaşdırılmışdır:
-	Hər bir DC motor şassinin yan hissələrinə yerləşdirilmişdir ki, torkun mərkəzə düzgün paylanması təmin olunsun.
-	Kodlayıcılar motorların düzgün oxuya bilməsi üçün mühərrik dişlilərinə yaxın, lakin hərəkət məhdudiyyətləri olmayan mövqedə quraşdırılmışdır.
-	Servo motorlar robotun xüsusi funksional hissələrinə yerləşdirilmişdir ki, hərəkət dəqiqliyi və sensor yönləndirməsi maksimal olsun.

Bu yerləşdirmə həm mexaniki balansı qoruyur, həm də sensorlardan və digər aktuatorlardan müdaxiləni minimuma endirir.



### Batareya və Ağırlıq Balansı

Robot şassisinin dizaynında batareya yalnız enerji təmin edən komponent kimi deyil, həm də ağırlıq mərkəzini optimallaşdıran element kimi nəzərə alınmışdır.
-	**Batareya yerləşimi:** 11.1V 3S Li-Po batareyası şassinin ortasına yaxın bir mövqedə yerləşdirilmişdir ki, robotun irəli-geri və yan hərəkətləri zamanı balans pozulmasın.
-	**Ağırlıq paylanması:** Bu yerləşdirmə motorlar, sensorlar və digər aktuatorların çəkisi ilə birgə robotun mərkəzi ağırlıq nöqtəsini aşağıda saxlayır, bu da daha stabil hərəkət və dönmə təmin edir.

Robotun mexaniki dizaynında enerji kabellərinin keçid trayektoriyası mühüm rol oynayır:
-	**Optimal marşrutlaşdırma:** Kabellər şassidə motorlardan, sensorlardan və Raspberry Pi-dən keçərkən həm hərəkət edən hissələrdən uzaq tutulur, həm də mexaniki müdaxilə riskini minimuma endirir.
-	**Gərginlik və təhlükəsizlik:** Kabellərin yönləndirilməsi zamanı mümkün qısaqapanma və sürtünmə nöqtələri nəzərə alınmış, naqillər üçün əlavə izolyasiya və kabel kanalları təmin edilmişdir.
-	**Servis rahatlığı:** Güc kabellərinin trayektoriyası, şassinin asan açılıb-qapanması və komponentlərin dəyişdirilməsi üçün nəzərdə tutulmuşdur.

Bu yanaşma mexaniki sabitliyi qoruyarkən, elektrik enerjisinin təhlükəsiz və səmərəli ötürülməsini təmin edir.

LIDAR və Kamera:
-	**Optimal yerləşim:** LIDAR sensoru robotun tam ortasına yaxın yerləşdirilmişdir ki, 360° əhatə təmin olunsun və maneələr tam şəkildə aşkarlansın. Kamera isə ön qisimdə, robotun baxış sahəsini maksimuma çıxaracaq şəkildə yerləşdirilmişdir.
-	**Stabil montaj:** Kamera üçün 4 ədəd ağ LED əlavə edilmişdir ki, robot işıq şəraitindən asılı olmayaraq rəngləri daha düzgün tanıya bilsin. Həm LIDAR, həm də kamera montajı möhkəm və vibrasiyadan qorunan standoff aralayıcılarla həyata keçirilmişdir.



IMU və Ultrasonik Sensorlar:
-	**Vibrasiyadan qoruma:** BNO055 IMU sensoru, robotun dönmə və hərəkət zamanı dəqiq məlumat verə biləcəyi üçün xüsusi amortizasiya təbəqəsi və montaj yerləri ilə yerləşdirilmişdir.
-	**Əyilmə minimallaşdırılması:** Ultrasonik sensor robotun arxa hissəsində, şassinin sabit bir nöqtəsinə montaj edilmişdir ki, hərəkət zamanı əyilmə və paralaks xətası minimum olsun.
-	**Optimal oxunuş:** Bütün sensorlar şassidə yerləşdirilərək məlumat axını və işləmə səmərəliliyi üçün optimal gərginlik səviyyələrinə uyğun trayektoriya ilə birləşdirilmişdir.

### Təkmilləşdirmə
-	**Öz motor sürücü kartının inteqrasiyası:** Robot əvvəlcə RRC Lite Controller-dən istifadə edirdi, lakin Raspberry Pi 5 ilə davamlı əlaqə problemləri səbəbindən öz motor sürücü kartımızı yaratdıq. Bu yeni kart mexanik şassi və digər komponentlərlə tam uyumlu şəkildə yerləşdirilmişdir, beləliklə robotun hərəkət və idarəetmə performansı artırılmışdır.
-	**Şassi və montaj dizaynının optimallaşdırılması:** Şassi, sensor və aktuator yerləşimi robotun spesifik ehtiyaclarına uyğunlaşdırılmışdır. Komponentlər həm funksional, həm də mexaniki baxımdan ən optimal yerlərə yerləşdirilmişdir; LIDAR robotun ön mərkəzində, gyro arxada, Raspberry Pi 5 və motor sürücü en arxa hissədə, ultrasonik sensor isə ən arxada yerləşir. Bu yerləşim robotun balansını, maneələrdən yayınma qabiliyyətini və sabit hərəkətini təmin edir.
-	**Texniki problemlərin həlli:** Əvvəlki sistemdə kabel ferritləri, kondensatorlar və güc xətlərinin optimallaşdırılması kimi tədbirlər sınanmışdır. Hər bir həll mexaniki və elektrik mühitində sınaqdan keçirilmiş, ən sonunda öz kartımızın hazırlanması ilə problemlər tam aradan qaldırılmışdır.
-	**Yaradıcı dizayn və adaptasiya:** Robotun mexanik və elektrik komponentlərinin inteqrasiyasında özəl həllər tətbiq edilmişdir. Bu, həm robotun funksionallığını artırmış, həm də sistemin etibarlılığını yüksəltmişdir.

<br>

<br>

### Nəticə
Mexaniki dizaynın nəticəsi olaraq, robotun bütün funksionallığı etibarlı şəkildə təmin edilmişdir. Şassi, sensorlar və aktuatorlar optimal şəkildə yerləşdirilmiş, vibrasiya və parazit minimuma endirilmişdir. Modul və optimallaşdırılmış struktur robotun həm prototipləşdirmə mərhələsində, həm də davamlı və uzunmüddətli istifadədə etibarlı performans göstərməsini təmin edir. Həmçinin, motor və sensor inteqrasiyaları, ağırlıq mərkəzinin balanslaşdırılması və kabel trayektoriyasının planlanması kimi mexaniki qərarlar, robotun stabil və səmərəli işləməsinə birbaşa töhfə vermişdir. Nəticədə, bu dizayn həm texniki effektivlik, həm də əməliyyat rahatlığı baxımından uğurlu sayılır.

# Proqram mühitinin hazıranması

### Raspberry Pi konfiqurasiyası

> Aşağıdakı əməliyyatları yerinə yetirə bilmək üçün kompüterinizə ən az `16GB` yaddaşı olan microSD kart taxmalısınız. Raspberry Pi əməliyyat sistemi bu karta yüklənəcək. **Əgər microSD kart içərisində fayllarınız varsa silinəcəklər**.

Biz Raspberry Pi üçün Ubuntu Server 24.04.3 LTS (64-bit) əməliyyat sistemini işlədirik. Bu əməliyyat sistemini mikrroSD kartına istədiyiniz kimi yükləyə bilərsiniz, ancaq məsləhət görülən üsul rəsmi Raspbery Pi saytından [Raspberry PI Imager tool](https://www.raspberrypi.com/software/) proqramını işlətməkdir. 

Raspberry PI Imager

Raspberry Pi modelinizi seçdikdən sonra "Əməliyyat sistemini seç" (Choose OS) düyməsinə basın. Bundan sonra `Other general-purpose OS` > `Ubuntu` > `Ubuntu Server 24.04.3 LTS (64-bit)` əməliyyat sistemini seçdirin.

Ubuntu Server 24.04.3 LTS (64-bit)

> Ubuntu Server 24.04.3 LTS (64-bit) Ubuntunun axırıncı server buraxılışıdır. Buna baxmayaraq bir çox Raspberry Pi modelini dəstəkləyir. Sırf bu buraxılışı işlətmək zəruri deyil, ancaq biz Ubuntu Server 24.04.3 LTS (64-bit) işlətdiyimizə görə sizə də bunu məsləhət görürük.

> Bu layihə üçünn Raspberry Pi OS (Raspbian) arzuolunan kimi işləmir. Bunun səbəbi layihədə `ROS2 Jazzy` paketinin işlədirməsidir. Hansı ki Raspberry Pi OS (Raspbian) tərəfindən dəstəklənmir.

İndi isə əməliyyat sistemini konfiqurasiya etmək üçün `Ctrl` `Shift` `X` və ya `⌘` `Shift` `X` düyməsinə sıxmalısınız. Açılan paneldə `General` hissəsinin aşağısında internetinizin adını, şifrəsini; Raspberry Pi üçün istifadəçi adını və şifrəsini konfiqurasiya edin. Bundan sonra `Services` hissəsinin aşağısında SSH və şifrə autentikasiyasına icazə verin. Beləcə Raspberry Pi alətinizə internetlə də qoşula bilərsiniz. Konfiqurasiya bitdikdən sonra `Next` düyməsini sıxın və yükləmə başlayacaq.

Yükləmə bitdikdən sonra mikroSD kartını Raspberry Pi - yə taxın. Raspberry Pi açıldıqdan sonra ona qoşulun və məsləhət görülür ki, bu iki komandanı verin:

```bash
$ sudo apt update
$ sudo apt upgrade
```

### İstifadə edilmiş paketlərin yüklənilməsi

`Git` proqramını yükləyərək başlayın. Bu paketi digər paketləri yükləmək üçün istifadə edəcəyik:

```bash
$ sudo apt-get install git
```

Raspberry Pi kamera modulunu istifadə etmək üçün (biz bu modulun üçüncü versiyasını işlədirik) `libcamera` və `rpicam-apps` paketləri yüklənməlidir.

Asılılıqları yükləyərək başlayın:

```bash
$ sudo apt install -y libboost-dev
$ sudo apt install -y libgnutls28-dev openssl libtiff5-dev pybind11-dev
$ sudo apt install -y meson cmake
$ sudo apt install -y python3-yaml python3-ply
$ sudo apt install -y libglib2.0-dev libgstreamer-plugins-base1.0-dev
```

İndi isə paket kodlarını yükləmək üçün:

```bash
$ git clone https://github.com/raspberrypi/libcamera.git
```

Əsas qovluğa keçin:

```bash
$ cd libcamera
```

Paket yüklənməsini konfiqurasiya etmək üçün:

```bash
$ meson setup build --buildtype=release -Dpipelines=rpi/vc4,rpi/pisp -Dipas=rpi/vc4,rpi/pisp -Dv4l2=true -Dgstreamer=enabled -Dtest=false -Dlc-compliance=disabled -Dcam=disabled -Dqcam=disabled -Ddocumentation=disabled -Dpycamera=enabled
```

Son olaraq `libcamera` paketini yükləmək üçün:

```bash
$ sudo ninja -C build install
```

`libcamera` paketi yükləndiyinə görə artıq `rpicam-apps` paketini yükləyə bilərik.

Yenə asılılıqlardan başlayırıq:

```bash
$ sudo apt install -y cmake libboost-program-options-dev libdrm-dev libexif-dev
$ sudo apt install -y meson ninja-build
```

Raspberry Pi `home/{istifadəçi adı}` qovluğuna keçin və paketin kodunu yükləyin: 

```bash
$ git clone https://github.com/raspberrypi/rpicam-apps.git
```

Paket qovluğuna keçmək üçün:

```bash
$ cd rpicam-apps
```

Yükləməni konfiqurasiya etmədən əvvəl `libav` paketini yükləyin ki kameradan video çəkmək mümkün olsun:

```bash
$ sudo apt install -y libavcodec-dev libavformat-dev libavutil-dev libswscale-dev libavdevice-dev libavfilter-dev
```

İndi isə yükləməni konfiqurasiya edin:

```bash
$ meson setup build -Denable_libav=enabled -Denable_drm=enabled -Denable_egl=disabled -Denable_qt=disabled -Denable_opencv=disabled -Denable_tflite=disabled -Denable_hailo=disabled
```

Artıq `rpicam-apps` paketini yükləyə bilərsiniz:

```bash
$ meson compile -C build
$ sudo meson install -C build
```

`ldconfig cache` - i yeniləyərək yükləməni bitirə bilərsiniz (bu əməliyyatı yüklədiyimiz paketləri başqa qovluqlarda da işlədə bilmək üçün yerinə yetiririk):

```bash
$ sudo ldconfig
```

Lazımlı paketləri yüklədiyinizə görə artıq `ROS2 Jazzy` inteqrasiyasını yükləyə bilərik.

[`ROS2 Jazzy`](https://docs.ros.org/en/jazzy/index.html) robot inteqrasiyası üçün istifadə olunan paketlər topluluğudur. Aşağıdakı instruksiyalar ilə bu paketlər toplusunu Raspberry Pi sisteminizə yükləyə bilərsiniz:

Raspberry Pi dilini konfiqurasiya edin:

```bash
$ locale 
$ sudo apt update && sudo apt install locales
$ sudo locale-gen en_US en_US.UTF-8
$ sudo update-locale LC_ALL=en_US.UTF-8 LANG=en_US.UTF-8
$ export LANG=en_US.UTF-8
$ locale 
```

Lazımlı proqramları yükləyə bilmək üçün `apt` paket idarəçisinə mənbələri əlavə edin:

```bash
$ sudo apt install software-properties-common
$ sudo add-apt-repository universe
```

İndi isə `ros2-apt-source` paketini əlavə edin:

```bash
$ sudo apt update && sudo apt install curl -y
$ export ROS_APT_SOURCE_VERSION=$(curl -s https://api.github.com/repos/ros-infrastructure/ros-apt-source/releases/latest | grep -F "tag_name" | awk -F\" '{print $4}')
$ curl -L -o /tmp/ros2-apt-source.deb "https://github.com/ros-infrastructure/ros-apt-source/releases/download/${ROS_APT_SOURCE_VERSION}/ros2-apt-source_${ROS_APT_SOURCE_VERSION}.$(. /etc/os-release && echo $VERSION_CODENAME)_all.deb" # If using Ubuntu derivates use $UBUNTU_CODENAME
$ sudo dpkg -i /tmp/ros2-apt-source.deb
```

Proqramlama mühiti üçün:

```bash
$ sudo apt update && sudo apt install -y \
  python3-flake8-blind-except \
  python3-flake8-class-newline \
  python3-flake8-deprecated \
  python3-mypy \
  python3-pip \
  python3-pytest \
  python3-pytest-cov \
  python3-pytest-mock \
  python3-pytest-repeat \
  python3-pytest-rerunfailures \
  python3-pytest-runner \
  python3-pytest-timeout \
  ros-dev-tools
```

`ROS2 Jazzy` emalatxanası düzəldin və lazım olan `ROS2 Jazzy` pakelərinin kodunu yükləyin:

```bash
$ mkdir -p ~/ros2_jazzy/src
$ cd ~/ros2_jazzy
$ vcs import --input https://raw.githubusercontent.com/ros2/ros2/jazzy/ros2.repos src
```

Bütün paketlərin son versiyada olduğuna əmin olmaq üçün:

```bash
$ sudo apt upgrade
```

Son olaraq hər şeyi yükləyin:

```bash
$ sudo rosdep init
$ rosdep update
$ rosdep install --from-paths src --ignore-src -y --skip-keys "fastcdr rti-connext-dds-6.0.1 urdfdom_headers"
```

`ROS2 Jazzy` sistemini yüklədikdən sonra layihə üçün paketləri yükləyə bilərik.

`ROS2 Jazzy` sistemini yükləmək onu işlətmək üçün bəs etmir. Hər işlətmək istənildikdə `/opt/ros/jazzy/setup.bash` komandası daxil edilməlidir. Əgər bunu etmək istəmirsinizsə bu komandanı `~/.bashrc` faylına əlavə edə bilərsiniz:

```bash
$ echo "source /opt/ros/jazzy/setup.bash">>~/.bashrc
```

Bu əməliyyatı icra etdikdən sonra terminalı yenidən başladın.

`camera_ros` paketi Raspberry Pi sisteminin kamerası ilə əlaqə saxlamaq üçün hazırlannmış `ROS2 Jazzy` paketidir. `camera_ros` paketini yükləmək üçün bu əməliyyatları icra edin:

```bash
$ cd ~/ros2_jazzy/src
$ sudo apt -y install python3-colcon-meson
$ git clone https://github.com/christianrauch/camera_ros.git
$ source /opt/ros/$ROS_DISTRO/setup.bash
$ cd ~/ros2_jazzy/
$ rosdep install -y --from-paths src --ignore-src --rosdistro $ROS_DISTRO --skip-keys=libcamera
$ colcon build --event-handlers=console_direct+
```

`rplidar_ros` isə Rplidar lidar sistemi ilə əlaqəyə keçmək üçündür. Onu yükləmək üçün:

```bash
$ cd ~/ros2_jazzy/src
$ git clone https://github.com/Slamtec/rplidar_ros.git
$ rosdep install -y --from-paths src --ignore-src --rosdistro $ROS_DISTRO --skip-keys=libcamera
$ colcon build --symlink-install
```

Paketləri yüklədikdən sonra istifadə edə bilmək üçün `~/ros2_jazzy/install/setup.bash` əməliyyatını icra etməlisiniz. Əgər bunu etmək istəmirsinizsə bu əməliyyatı `~/.bashrc` faylına əlavə edə bilərsiniz:

```bash
$ echo "source ~/ros2_jazzy/install/setup.bash">>~/.bashrc
```

### Kodun işlədilməsi və test edilməsi

Kodlarımızı işlətmək üçün kodunu endirin:

```bash
$ git clone https://github.com/coolboy19521/Voltivarius.git
$ cd Voltivarius/src
```

Əgər bütün fayllara baxsanız bu üç proqramı görəcəksiniz:

```bash
$ ls
MIAV.py run_MIAV.py color_selector_ros.py
```

Bu faylların ilki (`MIAV.py`) bizim raundlar üçün yazdığımız koddur və Raspberry Pi sistemində işləyir.

İkinci fayl (`run_MMIAV.py`) isə kodumuzu run etmək üçün olan ayrıca fayldır. Challange turunu etmək üçün bu faylı işə salmaq lazımdır.

Bu faylların axırıncısı (`color_selector.py`) rəng tanıma dəyərlərinin kalibrasiyası üçündür. Bu fayl isttifadəçinin kompüterində işlədilməlidir.

### Strategiyanın izahı

Strategiyanı izah etməzdən əvvəl robotumuzun bu strategiya üçün işlətdiyi alqoritmlərə baxaq:
- Maneənin tapılması:
  - Lidar sensor özünə ən yaxın və ən uzaq nöqtəni tapır. Bundan sonra əgər bu iki nöqtənin məsafəsi `5 sm` dən böyükdürsə deməli robotun qabağında maneə var. Bundan sonra maneənin çöl divara olan məsafəsi tapılır və bu məlumat işlədilərək maneənin robotun solunda yoxsa sağında olmağı anlaşılır. Bu nöqtələri taparkən lidar iç və çöl divara məsafəsi minimum `30 sm` olan və robotdan uzaqlığı robotun mərkəzindən `90 sm` radiusda olan nöqtələri nəzərə alır. Bu hazırda işlətdiyimiz alqoritmdir. Zaman mürəkkəbli `O(n)`.
  - Əvvəl işlətdiyimiz alqortimsə belədir: Robot özündən solda və ən uzaqda bir nöqtə tapır. Sonra bu nöqtəni referans nöqtəsi kimi istifadə edir və digər nöqtələri referans nöqtəsinə nisbətən koordinatlarıyla tanıyır. Sonra isə bütün nöqtələri qruplaşdırmağa çalışır (birbirinə məsfasə `5 sm` - dən kiçik olan nöqtələr eyni qrupa daxil olur). Əgər bizə ən yaxın olan qrupun tərəfləri uzunluğu `5 sm` - dən kiçikdirsə onda o maneədir. Bu alqoritmi işlətməməyimizin səbəblərindən biri `O(n^2)` zaman mürəkkəbliyində olmasıdır. Yeni işlətdiyimiz alqoritm sayəsində robot maneələrə daha həssasdır.
- Giroskop xətasının düzəldilməsi:
  - Robotumuz hərəkət edərkən həmişə əyilib əyilmədiyini yoxlayır. Bu dəyər kodda `gyro_angle = robot_car.read_gyro()` vasitəsilə alınır. Bundan sonra robot girospok xətası qədər dönüş edib özünü düzəltməyə çalışır. Ancaq dönüş edərkən `gyro_angle` qədər yox, PİD kontrollerindən alınan dəyər qədər dönüş edir. PİD kontroller robotların hərəkətinin tənzimlənməsi üçün istifadə olunan riyazi formuladır. Bizim kodumuzda PİD kontroller `pid.py` faylındadır.
  - İdeal dünyada sadəcə giroskop xətasını nəzərə almaq bəs etsə də, giroskoplar bəzən düzgünlüklərini itirə bilirlər. Biz robotumuzun zamanla hərəkət etdiyi istiqamətdə əyri getməyə başladığını gördük. Bundan sonra giroskop dəyərlərinə baxdıqda fikir verdik ki, robot əyri olduqda özünü düzmüş kimi görməyə başlayır. Bu problemi həll etmək üçün bir çox üsulu yoxladıq. İlk olaraq dönüşlərdən sonra robotun arxasını divara vurmağa qərar verdik. Bunu etməyimizin səbəbi odur ki, robot arxasını divara vurduqda giroskop robotun düşündüyündən nə qədər əyri olduğunu göstərirdi. Bu dəyəri aldıqdan sonra giroskopun aldığı yeni dəyərləri bu dəyərdən çıxmağa başlayırdır. Ancaq bu bizim üçün çox zaman itkisinə yol açırdı və biz üç dəqiqə limitinə sığa bilmirdik.
  - İkinci olaraq yoxladığımız üsul hər dönüşdən sonra robotun oxudğu giroskop dəyərinə əlavə dəyər artırmaq oldu. Məsələn əgər ikinci dönüş edildikdən sonra robot öz dərəcəsini `0°` olaraq görürsə biz bundan `4°` çıxırdıq və robot əslində dörd dərəcə əyri olduğunu anlayırdı. Bu üsul daha sürətli idi ancaq həm də riskli idi. Çünki hər dönüşdə robotun giroskop xətası eyni qədər olmurdu və həmişə eyni ədədi əlavə etmək bəzi problemlərə yol açırdı.
  - Son olaraq belə bir həll yolu tapdıq: Hər dönüşdən sonra robot çöl divarın özünə nisbətlə əyriliyini hesablayır və öz giroskop dəyərini buna görə dəyişir. Maneələr və robotun hərəkət istiqaməti hər zaman çöl divara paralel olduğuna görə bu üsul yaxşı işlədi. Çöl divarın robota nisbətən əyriliyini hesablamaq üçün robotun hərəkət istiqamətinin tərsində yerləşən, robotdan `15 sm` və `5 sm` uzaqda olan iki nöqtə tapırıq və bu nöqtələr arasındakı dərəcəni hesablayırıq. Bu üsulun tək pis cəhəti hər dönüşdən sonra LiDAR sensorun yenidən dəyər vermək üçün `500 ms` - yə ehtiyacı olmasıdır. Ancaq zaman limiti ilə bağlı problemimiz olmadığına görə bu həlli işlətməyə qərar verdik.

Alqoritmlərdən danışdığımıza görə indi maneə mərhələsi üçün strategiyamıza nəzər sala bilərik. Robotu park yerində başladırıq və robot təsvirdəki kimi park yerindən çıxıb maneə görənə qədər hərəkət etməyə başlayır:

Start_pos

<br>

Robot maneəni gördükdən sonra əvvəlcə ona paralel nöqtəyə dönür və maneəyə yaxınlaşır. Yaxınlaşdıqdan sonra maneənin rəngini kamerayla təyin edir və maneənin düzgün tərəfindən keçir (əgər maneə yaşıldır sol, əgər maneə qırmızıdırsa sağ):

Uc

<br>

İlk tur boyunca robot yuxarıdakı təsvirdəki kimi maneələrə yaxınlaşır və rənglərini oxuyur. Ancaq ikinci və üçüncü turda bunu artıq etmir. Çünki artıq bütün maneələrin rəngini görmüş olur:

Tc

Beləcə tur üçün sərf etdiyimiz zamanı **yarıya** endirmiş oluruq və sürətli hərəkətlərlə turları tamamlayırıq.

İlk tur üçün strategiyamızın diaqramına nəzər yetirə bilərsiniz:

Diagram of Strategy

### Robotun videoları

[Open Challange](https://www.youtube.com/watch?v=AVoUPSBA6hs)<br>
[Obstacle Challange](https://www.youtube.com/watch?v=ACrtoZzavfY)

**P.S. Kod, elektronika, mexanika və ya strategiya ilə bağlı hər hansısa sualınız olduqda bu GitHub hesabı və ya iştirakçıların mail hesabı ilə əlaqəyə keçə bilərsiniz.**

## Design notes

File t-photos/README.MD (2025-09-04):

<table cellspacing="0" cellpadding="0" style="margin:0; padding:0; border-collapse:collapse;">
  <tr>
    <td style="margin:0; padding:0;"><br></td>
    <td><br></td>
  </tr>
</table>

Our team consists of **Əhməd Qəmbərli** (Coding, Planning strategy, [ehmedqemberli09](mailto:ehmedqemberli09@gmail.com), rightmost in the official photo), **Melisa Yıldız** (General Design, [melisa.17.yildiz](mailto:melisa.17.yildiz@gmail.com), center in the official photo) and **Eyüp Şenal** (Electronics, Mechanics, Printing, Market research for used materials, [www.eyup.senal](mailto:www.eyup.senal@gmail.com), leftmost in the official photo). All of our team members have prior WRO experience in different categories.

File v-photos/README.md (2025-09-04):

## Photos & Videos of robot
<table cellspacing="0" cellpadding="0" style="margin:0; padding:0; border-collapse:collapse;">
  <tr>
    <td align="center" colspan="2">
      <br>
      <b>Right</b>
    </td>
    <td align="center" colspan="2">
      <br>
      <b>Left</b>
    </td>
  </tr>
  <tr>
    <td align="center">
      <br>
      <b>Up</b>
    </td>
    <td align="center">
      <br>
      <b>Front</b>
    </td>
    <td align="center">
      <br>
      <b>Back</b>
    </td>
    <td align="center">
      <br>
      <b>Down</b>
    </td>
  </tr>
</table>

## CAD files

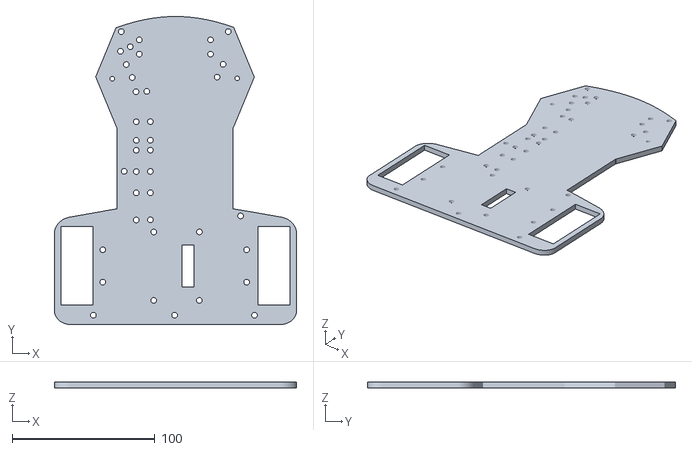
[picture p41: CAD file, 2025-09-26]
models/car_chassis_down_part.stl
170.0 x 216.0 x 4.00

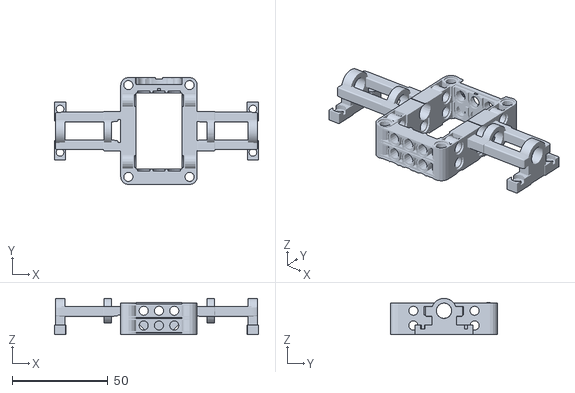
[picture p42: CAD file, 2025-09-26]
models/motor_box.stl
106.7 x 56.0 x 19.0

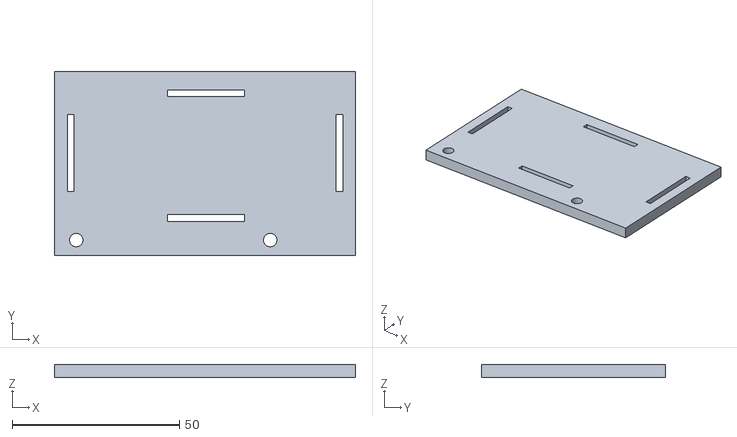
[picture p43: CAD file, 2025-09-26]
models/battery_holder.stl
90.0 x 55.0 x 4.00

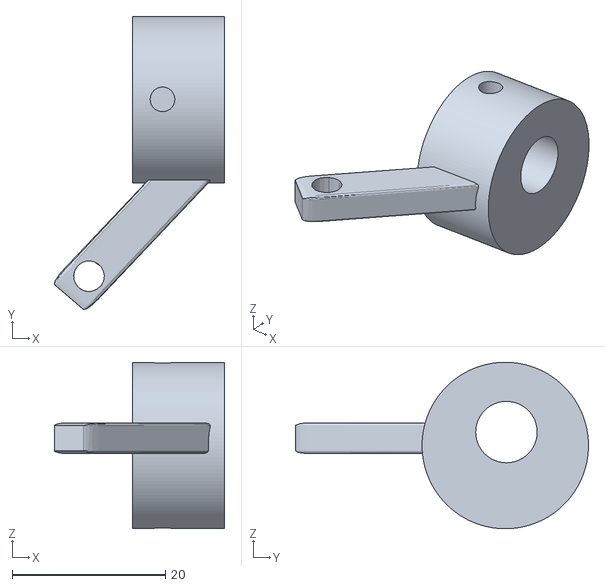
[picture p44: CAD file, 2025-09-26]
models/wheel_steering_system.stl
22.2 x 38.2 x 21.7

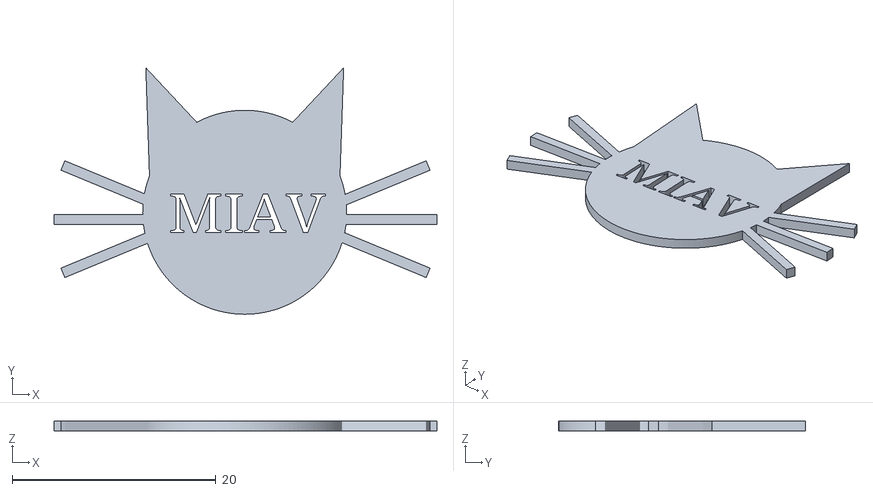
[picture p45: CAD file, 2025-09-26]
models/miav_cat.stl
37.6 x 24.2 x 1.00

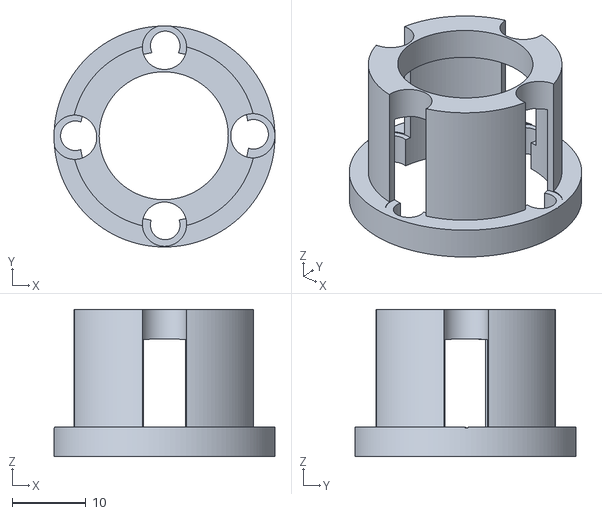
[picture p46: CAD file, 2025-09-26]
models/button_holder.stl
30.0 x 30.0 x 20.0

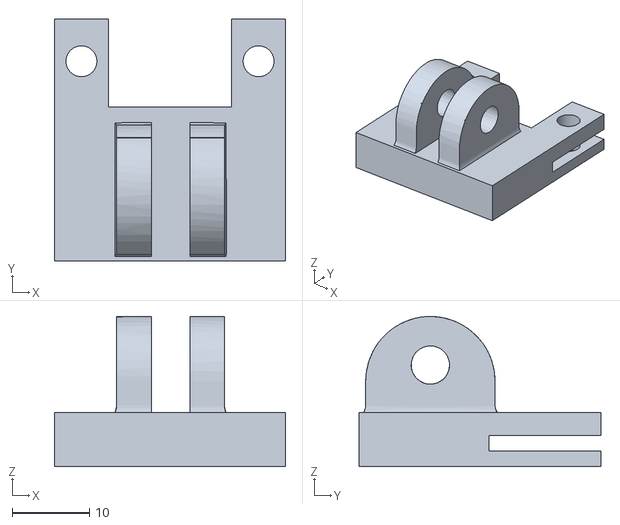
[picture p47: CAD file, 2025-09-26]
models/camera_holder_4.stl
30.0 x 31.4 x 19.5

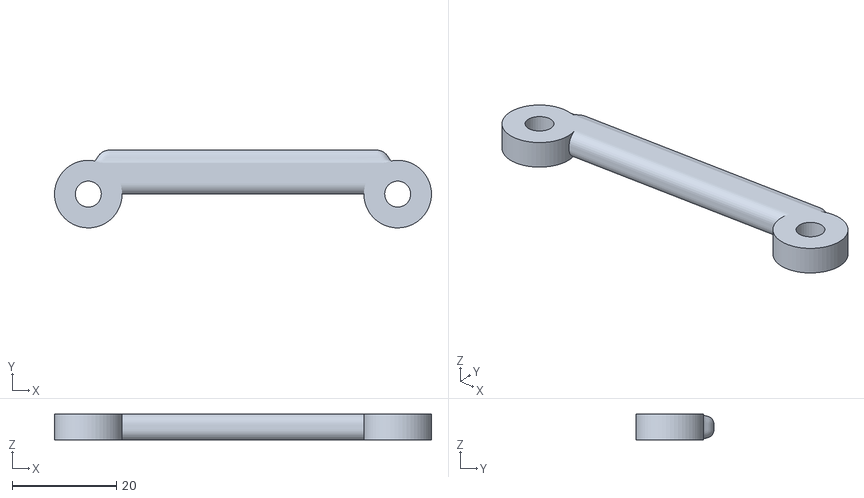
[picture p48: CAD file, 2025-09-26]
models/camera_holder_3.stl
72.5 x 15.0 x 4.91

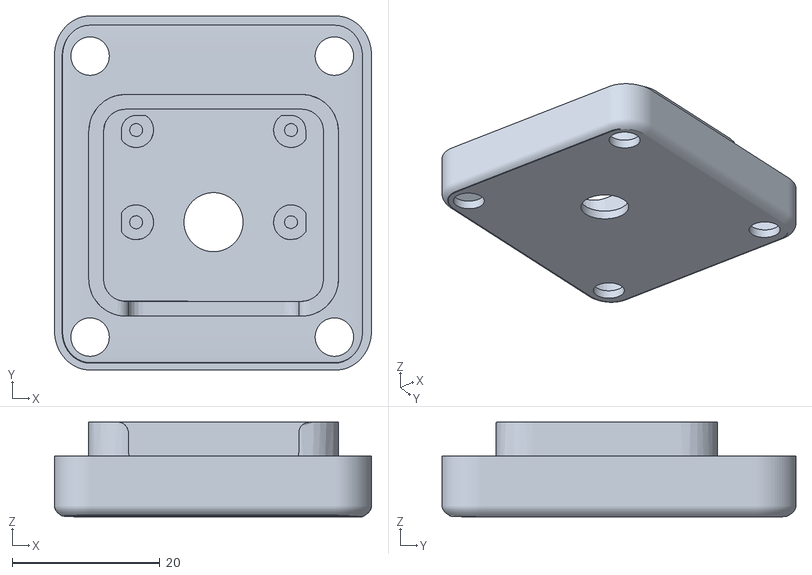
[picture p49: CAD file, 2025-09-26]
models/camera_holder_2.stl
43.0 x 48.0 x 12.9

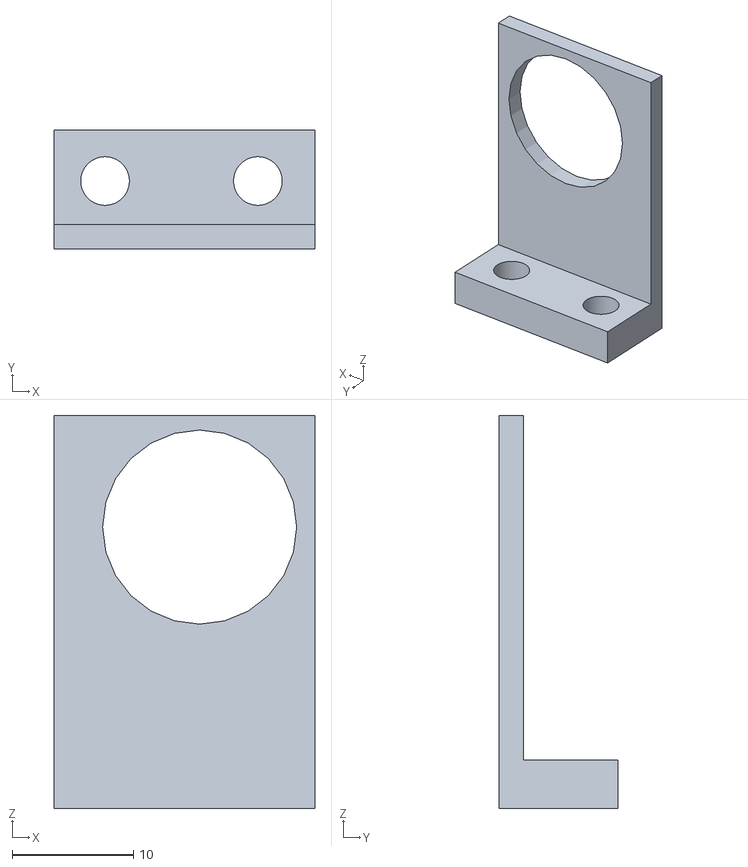
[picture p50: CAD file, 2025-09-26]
models/ultrasonic_holder.stl
21.5 x 9.80 x 32.4

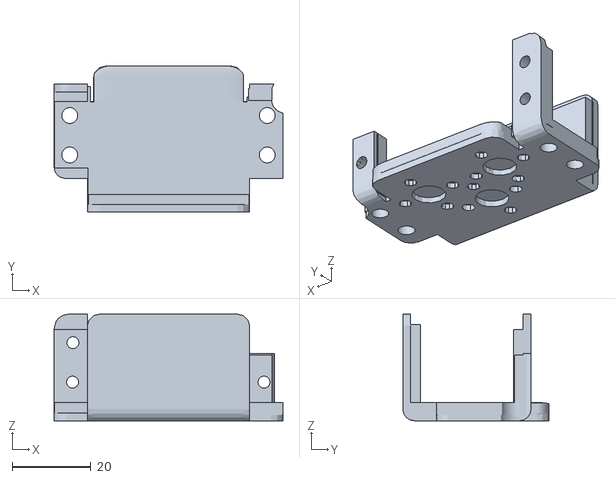
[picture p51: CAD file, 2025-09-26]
models/servo_motor_bracket.stl
58.0 x 37.1 x 27.0

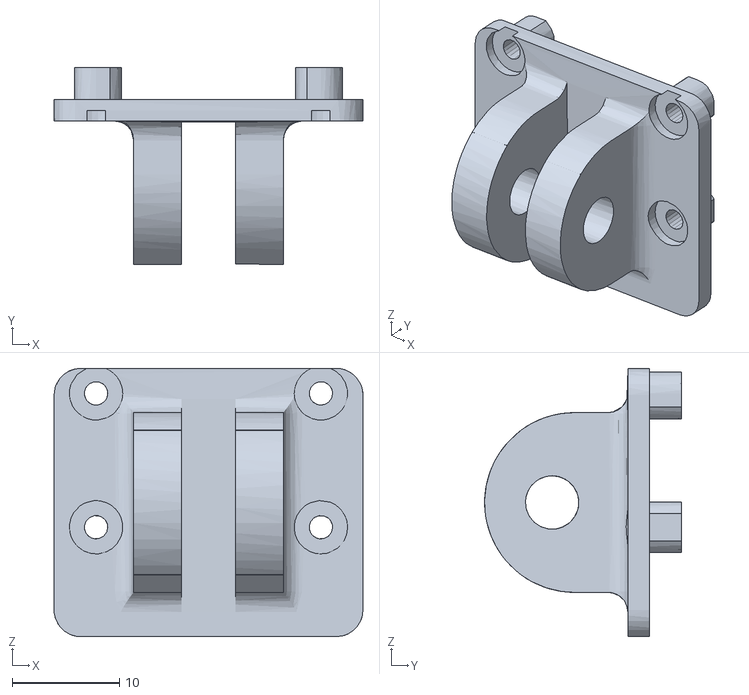
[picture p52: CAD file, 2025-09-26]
models/camera_holder_1.stl
28.9 x 18.4 x 25.1

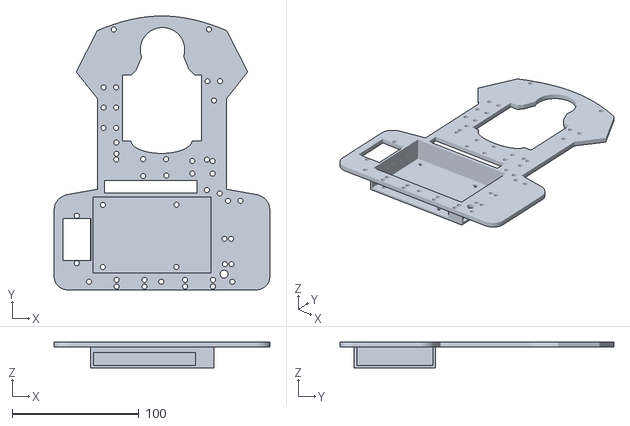
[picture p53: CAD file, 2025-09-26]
models/car_chassis_upper_part.stl
170.0 x 216.0 x 20.3

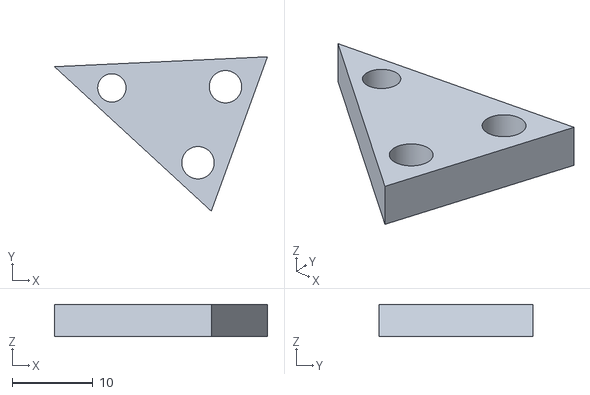
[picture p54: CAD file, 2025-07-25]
models/front_wheel_holder.stl
26.3 x 19.1 x 4.00

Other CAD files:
models/gear_box_wheel.stl
models/motor_box_wheel.stl
models/cable_holder.stl
models/wheel_steering_system_left.stl
models/Motor_box_cover.stl
models/Motor_box_v3.stl
models/motor_box_shaft_holder.stl
models/motor_box_wheel_ 62821.stl
models/motor_box_wheel_ 62821_2.stl
models/wheel_steering_system_right.stl

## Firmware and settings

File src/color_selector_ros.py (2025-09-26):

import rclpy
from rclpy.node import Node
from sensor_msgs.msg import CompressedImage
import cv2
import numpy as np
import color_lib

class CompressedImageViewer(Node):
    def __init__(self, mak):
        super().__init__('compressed_image_viewer')
        self.mak = mak
        self.mak.PrepareWindow()

        self.subscription = self.create_subscription(
            CompressedImage,
            '/camera/image_raw/compressed',
            self.listener_callback,
            10
        )

        self.frame = None
        self.frame_captured = False  # flag to store only the first frame

    def listener_callback(self, msg):
        if not self.frame_captured:
            np_arr = np.frombuffer(msg.data, np.uint8)
            frame = cv2.imdecode(np_arr, cv2.IMREAD_COLOR)
            if frame is not None:
                self.frame = frame.copy()
                self.frame_captured = True

    def process_loop(self):
        if self.frame is None:
            return

        while True:
            self.mak.BruteForce(self.frame)
            if cv2.waitKey(1) & 0xFF == ord('q'):
                break

def main(args=None):
    rclpy.init(args=args)
    mak = color_lib.DataMaker()
    node = CompressedImageViewer(mak)

    try:
        while not node.frame_captured:
            rclpy.spin_once(node)
        node.process_loop()
    except KeyboardInterrupt:
        pass
    finally:
        node.destroy_node()
        rclpy.shutdown()
        cv2.destroyAllWindows()

if __name__ == '__main__':
    main()

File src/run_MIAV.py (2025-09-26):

from MIAV import miav
from gpiozero import Button
from rclpy import init, spin, shutdown

but = Button(23)

def main():
    init()
    node = miav()
    print('Running')
    try:
        spin(node)
    #except Exception as e:
    #    print(e)
    finally:
        node.destroy_node()
        shutdown()

if __name__ == '__main__':
    but.wait_for_press()
    main()

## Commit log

2025-07-25 Models uploaded
    [Moto_box_wheel_ 62821.stl, Motor_box_cover.stl, Motor_box_v3.stl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]
2025-07-28 Raspberry SSH trial
2025-07-28 Virtual environment created (matplotlib, rplidar, pyserial installed). Lidar set up.
2025-07-29 Camera streaming via flask added
2025-07-29 Created .gitignore and also fixed issue of overlapping camera and lidar code.
2025-08-01 gpiozero installed and tested (additionally gyro tested)
